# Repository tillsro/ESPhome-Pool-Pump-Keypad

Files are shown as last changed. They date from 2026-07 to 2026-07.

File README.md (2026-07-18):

# iLiving / Lingxiao Variable-Speed Pool Pump Controller

This repository documents and implements the proprietary RS-485 link between
the removable keypad and motor controller in an **iLiving ILG8PP390-VS** pool
pump. It contains:

- a PowerShell controller proven against the real pump;
- an ESPHome component for an M5Stack AtomS3 and Atomic RS485 Base;
- a PC pump emulator for testing either the AtomS3 or original keypad; and
- logic captures and keypad firmware analysis used to recover the protocol.

This project began with a more conventional approach. The iLiving manual
advertises an external RS-485 mode compatible with Pentair automation, so we
first tried the existing
[`gazoodle/CenturyVSPump`](https://github.com/gazoodle/CenturyVSPump) ESPHome
component. That project controls Century/Regal VGreen-style motors after they
are placed into a specific automation protocol mode. We could not put the
tested iLiving pump into any state that accepted those commands. Rather than
continue guessing at an inactive external interface, we switched to the link
we could prove was working: communication between the removable keypad and the
motor controller. Emulating that keypad became the basis of this project.

The protocol is not standard Modbus RTU. It uses a Modbus CRC-16, but it has no
Modbus address, function code, or register map.

## Safety

Pool pumps combine mains voltage, water, rotating equipment, and stored charge.
Work on the low-voltage communication connector only, with pump power removed
while changing wiring. Follow the pump manual and use a qualified electrician
for mains wiring.

- Disconnect the original keypad before another device transmits on its bus.
- Never connect two RS-485 transmitters to the pump at the same time.
- Do not connect the pump cable's `+5V` wire to the Waveshare adapter.
- Do not connect the pump's `+5V` wire to the Atomic base's `DC24V` terminal.
- Confirm polarity and protocol passively before sending commands to an
  untested model.
- The supplied ESPHome configuration defaults to sending a stop demand after
  boot. Read its startup-mode notes before installing it on operating equipment.

This is an independent reverse-engineering project. It is not affiliated with
or endorsed by iLiving, Guangdong Lingxiao Pump Industry, M5Stack, or the other
brands named below.

## Current Status

| Path | Result |
|---|---|
| Waveshare USB-RS485 -> real ILG8PP390-VS | **Confirmed:** complete replies, 1400/1800/2000 RPM, stop, and restart |
| Original keypad -> real ILG8PP390-VS | **Confirmed:** captured and decoded at startup, prime, presets, custom speeds, and stop |
| AtomS3 + Atomic RS485 Base -> PC emulator | **Confirmed:** 204/204 requests accepted in the recorded bench run; start, stop, RPM ramping, faults, and offline handling tested |
| Original keypad -> PC emulator | **Confirmed:** prime behavior and all 11 documented faults tested |
| AtomS3 + Atomic RS485 Base -> real pump | **Confirmed:** direct communication and pump control using pump `485A+` -> Atomic `A` and pump `485A-` -> Atomic `B` |

The original keypad uses an STM32F030-family MCU. Its flash was read twice with
matching output at RDP Level 0, without erase, unlock, or write operations.

## How We Reverse Engineered It

After the external-automation approach failed, we did not have a known register
map or a service manual for the keypad link. We had a six-wire cable, a running
pump, and a detachable keypad whose traffic had to be observed without
disrupting it. The final protocol came from combining electrical measurements,
controlled captures, failed replay experiments, firmware analysis, and
physical pump tests. No single method was sufficient by itself.

### Hardware and tools

| Item | How it was used |
|---|---|
| iLiving `ILG8PP390-VS` and original keypad | Reference system for every known-good state and final command test |
| Breakout connector and soldered PCB tap points | Allowed the keypad to be connected or isolated while the bus was monitored |
| Waveshare USB TO RS485 adapter | Captured byte streams and later transmitted generated pump commands |
| FX2LP Saleae-compatible logic analyzer | Passively observed both differential pairs and verified baud rate, polarity, and timing |
| ST-Link V2 clone | Read the keypad MCU and inspected live SRAM over SWD |
| STM32CubeProgrammer 2.22 | Identified the MCU, checked RDP, read flash, and performed read-only HotPlug memory inspection |
| PulseView and `sigrok-cli` | Recorded and decoded the logic-analyzer captures |
| PowerShell | Automated repeated captures, timestamped serial logging, frame replay, timing, and reply validation |
| Python | Implemented the stateful pump emulator and repeatable protocol tests |
| M5Stack AtomS3 and Atomic RS485 Base | Exercised the ESPHome controller against both the PC emulator and real pump |

### Establishing the physical bus

The keypad harness is labeled `485A+`, `485A-`, `485B+`, `485B-`, `GND`, and
`+5V`. The first byte captures were misleading because the keypad was talking
without a pump and was already in its communication-error behavior. We also
learned that matching the Waveshare `A+` and `B-` labels directly to the pump
labels inverted the data. The working mapping had to be established
empirically and then checked against the logic analyzer.

Once tap points and a disconnectable harness were available, the logic analyzer
could listen while the original keypad and pump communicated normally. The
Waveshare was disconnected during passive captures so it could not contend for
the bus. Probing all four data wires showed that normal keypad polling was on
the `485A` pair. The `485B` pair remained silent during those captures.

One especially useful experiment was to unplug the keypad while leaving the
pump running and listen to the bus. The pump sent nothing by itself. That
established that the keypad is the polling master and the drive only replies
after a request. It also explained why simply opening a serial port and waiting
could never discover the pump protocol.

### Capturing behavior instead of guessing fields

The inexpensive FX2LP analyzer could record only about 600 ms before hitting
its capture limit. `loop-capture.ps1` worked around that limitation by launching
many short `sigrok-cli` captures back to back. We recorded the pump in known
states rather than collecting one long, unlabeled trace: each preset, custom
speeds from 1000 through 3450 RPM, a speed transition, a complete shutdown, a
power-on transition, and the start of the ten-minute prime cycle.

Those controlled changes let us correlate bytes with real behavior. They also
established the approximately 61 ms request cadence and the pump's reply timing.
The shutdown and startup captures were particularly valuable because they
contained state transitions that did not appear at a steady speed.

### The convincing 9600-baud false lead

Our first UART decode at 9600 baud produced repeatable-looking `B5`, `A5`, `BD`,
and `F6` messages. Some apparent requests were three bytes, others four or five.
Because the same patterns appeared across captures, they looked like a real
variable-length protocol. We classified the messages, replayed captured prime
sequences, and tried to associate individual bytes with speed.

The pump did not accept those replays. Several practical mistakes made the
failure harder to interpret: some early emulator tests still had the original
keypad transmitting on the bus, and `Start-Sleep -Milliseconds 1` on Windows
actually introduced delays around 15 ms, far too coarse for the observed
timing. After eliminating bus contention and replacing sleeps with stopwatch
timing, the replay still failed. That forced us to question the decode itself.

The important lesson was that a UART alias can look structured and repeatable.
The apparent 9600-baud frames were a decoding artifact, not random noise, so
frequency tables and repeated patterns alone were not enough to validate them.

### Reading the keypad firmware safely

The keypad PCB exposed pads labeled `NRST`, `SWD`, `SWK`, `GND`, and `3.3V`.
Before connecting the ST-Link, we treated `3.3V` as the debugger's target-voltage
reference and explicitly avoided any unlock or erase operation. STM32CubeProgrammer
identified an STM32F05x/F030x8-class Cortex-M0 with 64 KB of flash and RDP Level
0. Two complete reads produced the same SHA-256 hash, giving us a verified
backup before any live inspection.

Static firmware analysis found two initialized UART stacks. `USART2` built a
request roughly every 60 ms and had a recognizable transmit buffer. `USART1`
used a separate parser and command family, which is why the silent `485B` pair
is still treated as a possible service or external-control interface rather
than declared unused.

Read-only HotPlug SRAM reads then connected the firmware to physical keypad
actions. While the keypad remained attached to the real pump, selecting the
three presets changed the `USART2` value field to `0x0C3A`, `0x0982`, and
`0x1770`, corresponding to 1800, 1400, and 3450 RPM on this keypad. The live
buffer showed a 12-byte structure beginning with `01 70`, a sequence byte, a
big-endian demand value, and a little-endian additive checksum. Comparing more
speeds revealed the scaling rule `floor(RPM * 6000 / 3450)`.

This was the point where firmware became a second source of truth. It disproved
the old 9600-baud interpretation and gave us exact bytes to search for in the
electrical captures. Re-decoding the bus at 38400 baud with the correct inverted
polarity exposed the same `01 70` traffic on the wire.

### Finding the missing on-wire bytes

The firmware buffer explained the first 12 bytes but not the whole transmitted
request. Comparing candidate frames with the captured tail bytes showed that a
standard Modbus CRC-16 was appended after the additive checksum. The complete
request was therefore 14 bytes, not 12. The same construction appeared at the
end of the pump response: 34 data bytes, a two-byte additive checksum, and a
two-byte Modbus CRC, for 38 bytes total.

That correction was the breakthrough. A replay containing the 12-byte inner
frame plus the CRC received a valid 38-byte response on its first request. The
reply parser was then made deliberately strict: it searches arbitrary serial
chunks for `01 70`, checks the expected sequence and shape, verifies the
additive checksum, and finally verifies the CRC. Single `00` bytes and partial
USB reads are treated as noise instead of pump acknowledgements.

### Proving control on the real pump

With the original keypad disconnected, the Waveshare sent sustained 14-byte
requests at the observed cadence. The pump returned complete replies and was
physically confirmed at 1400, 1800, and 2000 RPM. A zero demand stopped the
motor, and a later 1800 RPM demand restarted it. One timing soak returned 120
valid replies for 120 requests with no noise bytes.

Those tests also identified useful reply fields. The pump reports its accepted
demand at bytes `12..13`, an actual-speed value at `14..15`, and an echo of the
requested demand at `32..33`. Stop and restart captures showed those fields
ramping down and back up with the motor rather than changing only in software.

### Testing both sides without the pump

After the real control path worked, `pump_emulator.py` was built from a captured
38-byte response. It validates keypad/controller requests, echoes the sequence
and demand, simulates acceleration and deceleration, and can inject dropped
replies, bad CRCs, offline periods, and documented fault codes.

Connecting the original keypad to that emulator provided an independent test of
the reply direction. The keypad entered prime, commanded 3450 RPM, accepted the
simulated speed ramp, and displayed all 11 injected fault codes. It also exposed
the keypad's fault workflow: one power-button press acknowledges the error and
leaves the pump off; a second press starts prime again.

Finally, the AtomS3 and Atomic RS485 Base were connected to the same emulator.
The recorded bench run accepted and answered 204 of 204 requests while the
display followed stop, ramp, run, fault, and offline states. Protocol fixtures
and Python tests now preserve the request, reply, checksum, CRC, scaling, fault,
and stream-recovery behavior that was learned from the hardware.

The AtomS3 was then connected to the real pump with pump `485A+` wired to Atomic
`A`, pump `485A-` wired to Atomic `B`, and a shared ground. Direct communication
and pump control were confirmed on 2026-07-15. This closes the final
AtomS3-to-real-pump validation gap while keeping the PC emulator available for
tests that do not need a running motor.

## Protocol Summary

### Electrical and timing

- Physical layer: half-duplex RS-485
- Active keypad pair: `485A+` / `485A-`
- Serial format: 38400 baud, 8 data bits, no parity, 1 stop bit
- Request cadence: approximately 61 ms
- Keypad role: master; the pump remains silent until polled
- Request length: 14 bytes
- Reply length: 38 bytes

The earlier apparent 9600-baud `B5/A5/BD/F6` traffic was a logic-analyzer decode
alias. Valid captures decode as 38400 8N1 with inverted polarity on the probed
`485A+` channel.

### Request

```text
01 70 <seq> <status> 00 0C 00 00 <value_hi> <value_lo> <sum_lo> <sum_hi> <crc_lo> <crc_hi>
```

| Bytes | Meaning |
|---|---|
| `0..1` | Fixed header `01 70` |
| `2` | Sequence number |
| `3` | Status/control byte; zero in the validated command path |
| `4..7` | Fixed shape bytes `00 0C 00 00` |
| `8..9` | Big-endian speed demand value |
| `10..11` | Little-endian 16-bit sum of bytes `0..9` |
| `12..13` | Little-endian Modbus CRC-16 of bytes `0..11` |

The speed conversion is:

```text
value = floor(RPM * 6000 / 3450)
RPM   = value * 3450 / 6000
```

`value = 0` stops the motor. Known values include `0x0982` for 1400 RPM,
`0x0C3A` for 1800 RPM, and `0x1770` for 3450 RPM.

### Reply

The complete reply is validated before any state is accepted:

| Bytes | Meaning used by this project |
|---|---|
| `0..1` | Header `01 70` |
| `2` | Echoed sequence |
| `3` | Pump fault code, zero when clear |
| `4..5` | Shape bytes `00 0C` |
| `12..13` | Accepted demand value, big-endian |
| `14..15` | Actual speed value, big-endian |
| `32..33` | Echoed demand value, big-endian |
| `34..35` | Little-endian 16-bit sum of bytes `0..33` |
| `36..37` | Little-endian Modbus CRC-16 of bytes `0..35` |

Several reply fields remain unnamed. Captures from more operating conditions
are welcome; do not assign meanings from a single changing sample.

## Internal Keypad Bus vs. External Automation

The iLiving manual describes an external RS-485 mode compatible with Pentair
automation and says external keypad and RS-485 control are mutually exclusive.
That interface must not be confused with the internal `01 70` keypad protocol
implemented here.

Before reverse-engineering the internal bus, we attempted to use
[`CenturyVSPump`](https://github.com/gazoodle/CenturyVSPump) through that
documented external-control path. We were never able to place the tested pump
in a mode that accepted its commands. This does not show that the upstream
component is faulty; it shows only that its expected Century/Regal automation
mode was not accessible on our iLiving hardware. The known-active keypad bus
therefore became the practical control path.

The removable keypad cable has two differential pairs. `485A` carries the
confirmed `01 70` traffic. `485B` is silent during normal passive captures, but
the dumped keypad firmware initializes a second UART and a separate command
parser. It is plausible that this relates to an external or service interface,
but its physical mapping and protocol have not been proven.

Pentair, Jandy, and Hayward pumps are therefore **not** implied to be compatible
with this project merely because related Lingxiao pumps can connect to those
automation systems.

## Compatibility Research

Research was last refreshed on **2026-07-13**. Compatibility labels mean:

- **Confirmed**: this exact model exchanged valid `01 70` frames on hardware.
- **OEM-family candidate**: manufacturer documentation, certification data, or
  an FCC model declaration places it in the same pump family. The internal bus
  still needs a passive capture before use.
- **Similar-controller candidate**: the keypad, operating behavior, and fault
  table closely match, but no direct OEM-family declaration was found.

| Confidence | Brand / series | Models | Evidence | Internal `01 70` protocol |
|---|---|---|---|---|
| Confirmed | iLiving | `ILG8PP390-VS` | Physical captures, firmware analysis, and successful control in this repository | Confirmed |
| OEM-family candidate | iLiving | `ILG8PP130-VS`, `ILG8PP220-VS` | Same official three-model manual, controller description, speed range, prime behavior, and fault table | Unverified |
| OEM-family candidate | LX / Key Lander | `SHP130-VS`, `SFP220-VS`, `SWP390-VS` | Lingxiao product/certification records and the same model-family manuals | Unverified |
| OEM-family candidate | Lingxiao Relaax | `Relaax130-VS`, `Relaax220-VS`, `Relaax390-VS` | Manufacturer identity, matching certifications, and Lingxiao's FCC model declaration | Unverified; revision risk |
| OEM-family candidate | Trevi / Innovaqua | `SPH130-VS`, `SPH220-VS`, `SPH390-VS` | Official manual has the same controller, defaults, 10-minute prime, and 11-code fault table; Trevi lists the underlying `SFP220-VS` / `SWP390-VS` model names | Unverified |
| OEM-family candidate | Aqua Expert | `VSP13-Pro`, `VSP22-Pro`, `VSP39-Pro` | Included in Lingxiao's FCC model declaration and matching ENERGY STAR performance records | Unverified; current products add Wi-Fi |
| OEM-family candidate | Illuminex AquaPump | `LU-VS130`, `LU-VS220`, `LU-VS390` | Included in Lingxiao's FCC model declaration; official manual and specifications match the family | Unverified; current products add Wi-Fi |
| Similar-controller candidate | Trevoli SPV | `SPV100`, `SPV200`, `SPV300` | Distributor manual shows the same 1.3/2.2/3.9 HP grouping, 450-3450 RPM range, keypad behavior, prime cycle, defaults, and fault table | Unverified; OEM relationship not established |

The EPA ENERGY STAR dataset gives the iLiving, Lingxiao/LX/Key Lander, Trevi,
and Aqua Expert equivalents identical certified performance values within each
horsepower class. For example, all researched 3.9 HP entries report WEF `7.262`,
HHP `1.808`, and the same low/high test-point RPM and flow values. This is strong
evidence of a shared hydraulic and drive platform, but it is not proof that every
controller revision runs the same serial firmware.

### Revision risk

The newer Lingxiao manual filed with the FCC groups all three horsepower classes
and the iLiving, Relaax, SPH, VSP, and LU aliases under one model declaration.
It also adds Smart Life Wi-Fi support and fault codes not present in the older
iLiving keypad manual (`E030`, `E040`, `E095`, and `LOF`). A visually identical
or identically named pump may therefore contain a newer controller revision.

No public implementation or register map for the internal `01 70` protocol was
found under the researched iLiving or Lingxiao model numbers. Do not describe
this protocol as a known Modbus register set.

## Identifying Another Pump Safely

1. Record the exact brand, model, serial label, controller label, keypad photos,
   connector labels, and manual revision.
2. Compare its speed range, preset defaults, 10-minute prime behavior, and fault
   table with the documents linked below.
3. With pump power off, identify ground and measure supply voltage before
   attaching any analyzer. Do not infer pinout from wire color.
4. Reconnect the original keypad and capture passively. A logic analyzer may
   listen in parallel, but a USB-RS485 adapter must not transmit.
5. Look for 14-byte `01 70` requests every approximately 61 ms at 38400 8N1 and
   38-byte replies with valid additive checksums and Modbus CRC-16.
6. If that fingerprint differs, stop. Add a new protocol variant instead of
   trying this controller unchanged.
7. For a matching fingerprint, disconnect the keypad and make the first active
   test with a zero-speed demand while watching the pump and serial reply.

To test only a detached keypad without connecting its pump, follow the
[`Offline Keypad Compatibility Test`](docs/keypad-compatibility-test.md). It
checks both validated keypad requests and the keypad's handling of complete
speed, state, and fault replies.

Appearance alone is not enough. Product certification tables can also place
unrelated models next to one another; only explicit family evidence and a bus
capture should move a model into the supported list.

## Hardware and Wiring

### Proven Waveshare-to-pump wiring

The following mapping is specific to the labels on the tested iLiving harness:

| Pump cable | Waveshare USB TO RS485 |
|---|---|
| `485A-` | `A+` |
| `485A+` | `B-` |
| `GND` | `GND` |
| `+5V` | Not connected |
| `485B+`, `485B-` | Not connected for normal keypad emulation |

The crossed labels were established empirically on this pump. They do not mean
all RS-485 products use reversed labels.

For passive logic capture, the tested channel assignment is:

| Pump cable | Logic analyzer |
|---|---|
| `485A-` | `D0` |
| `485A+` | `D1` |
| `485B-` | `D2` |
| `485B+` | `D3` |
| `GND` | `GND` |

The usable UART stream decodes on `D1` with RX inversion enabled.

### Proven AtomS3-to-pump wiring

This mapping was validated on the real iLiving ILG8PP390-VS on 2026-07-15:

| Pump cable | Atomic RS485 Base |
|---|---|
| `485A+` | `A` |
| `485A-` | `B` |
| `GND` | `G` |
| `+5V` | Not connected |
| `485B+`, `485B-` | Not connected |

Power the AtomS3 through USB-C. Leave the Atomic base's `DC24V` terminal
disconnected; the pump's `+5V` wire is not a suitable input for that terminal.

### PC emulator to Atomic RS485 Base

For an isolated bench setup with no pump or keypad connected:

| Waveshare USB-RS485 | Atomic RS485 Base |
|---|---|
| `A+` | `A` |
| `B-` | `B` |
| `GND` | `G` |

Power the Waveshare and AtomS3 through their own USB connections. Leave the
Atomic base's `DC24V` terminal disconnected.

### Hardware photos and M5Stack adapter plate

These photos document the tested pump electronics, communication connector,
and the finished AtomS3 installation. The controller is mounted in a custom
3D-printed adapter plate that measures 115 x 115 mm overall and holds the
AtomS3 and Atomic RS485 Base behind the panel.

This is the original removable iLiving keypad used for the protocol captures,
STM32 firmware analysis, real-pump reference tests, and offline emulator tests:

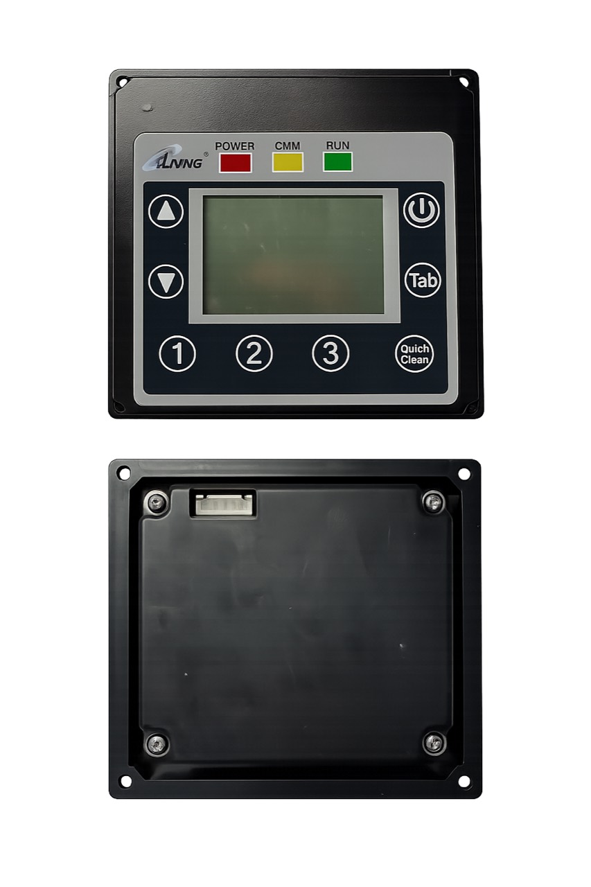
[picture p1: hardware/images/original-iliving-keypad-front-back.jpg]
Front and rear views of the original iLiving pool pump keypad


| Pump controller board | Communication connector detail |
|---|---|
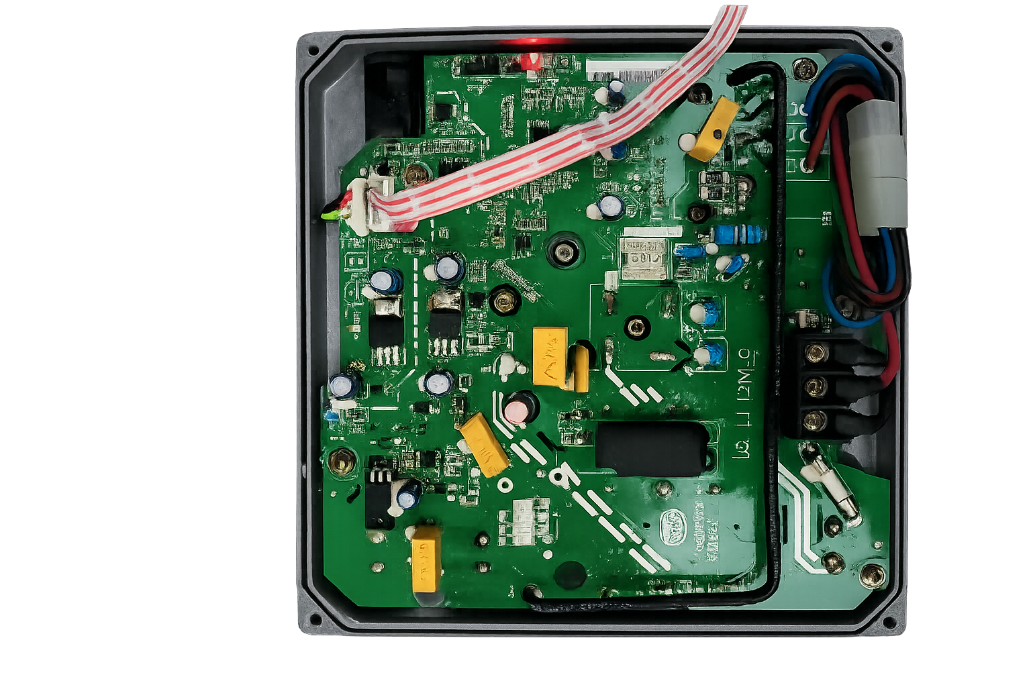
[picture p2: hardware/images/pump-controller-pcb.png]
Pump controller board inside its enclosure
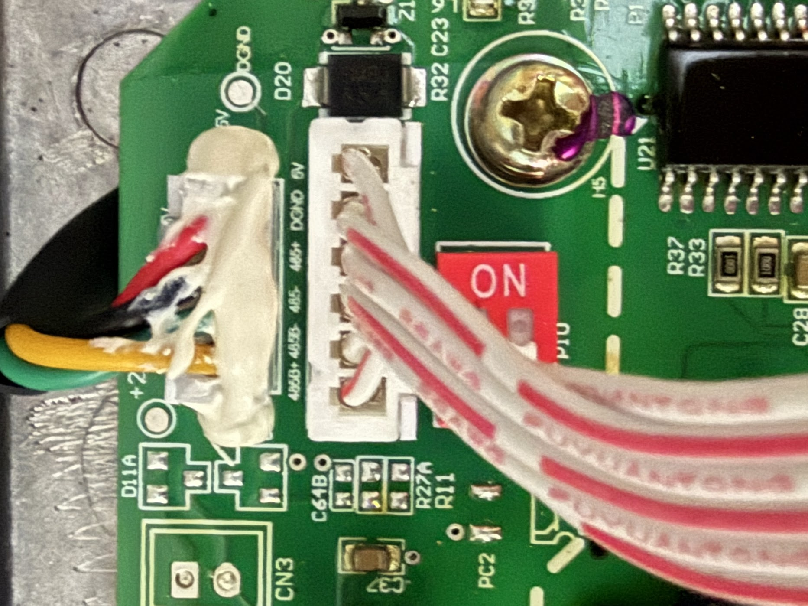
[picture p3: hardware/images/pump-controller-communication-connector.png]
Close-up of the pump controller communication connector and PCB labels
|  |  |

| Finished adapter plate | Adapter plate interior |
|---|---|
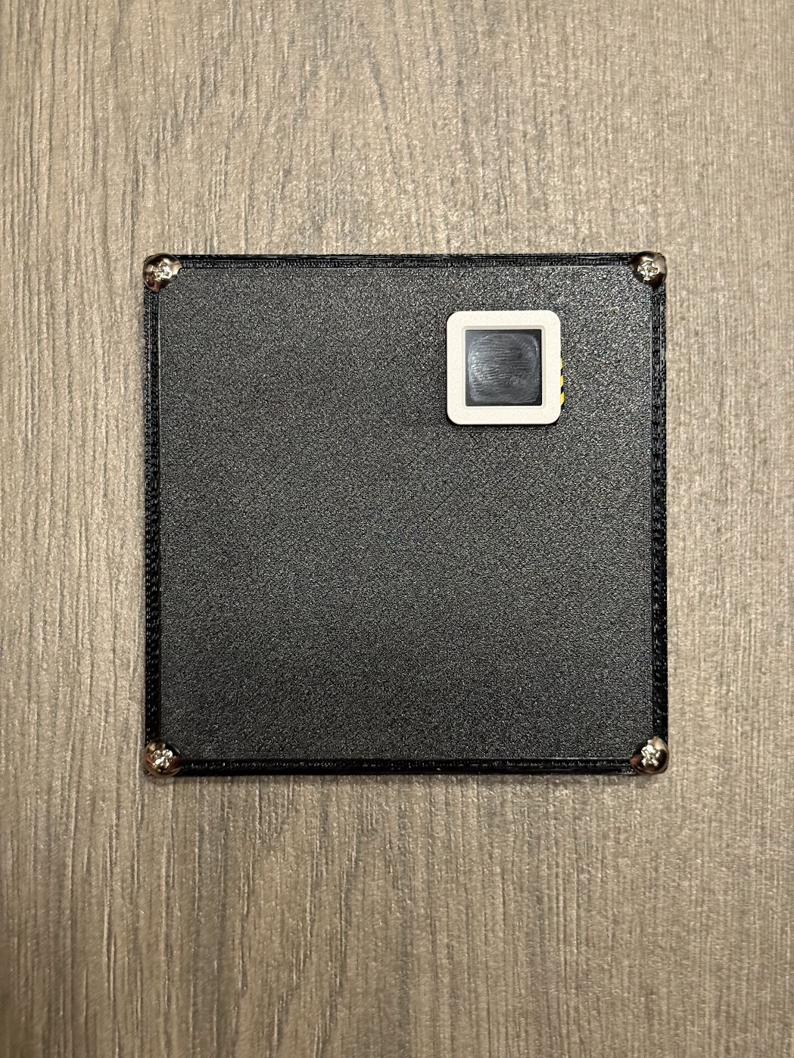
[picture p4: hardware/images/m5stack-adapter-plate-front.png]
Front of the printed M5Stack adapter plate with AtomS3 installed
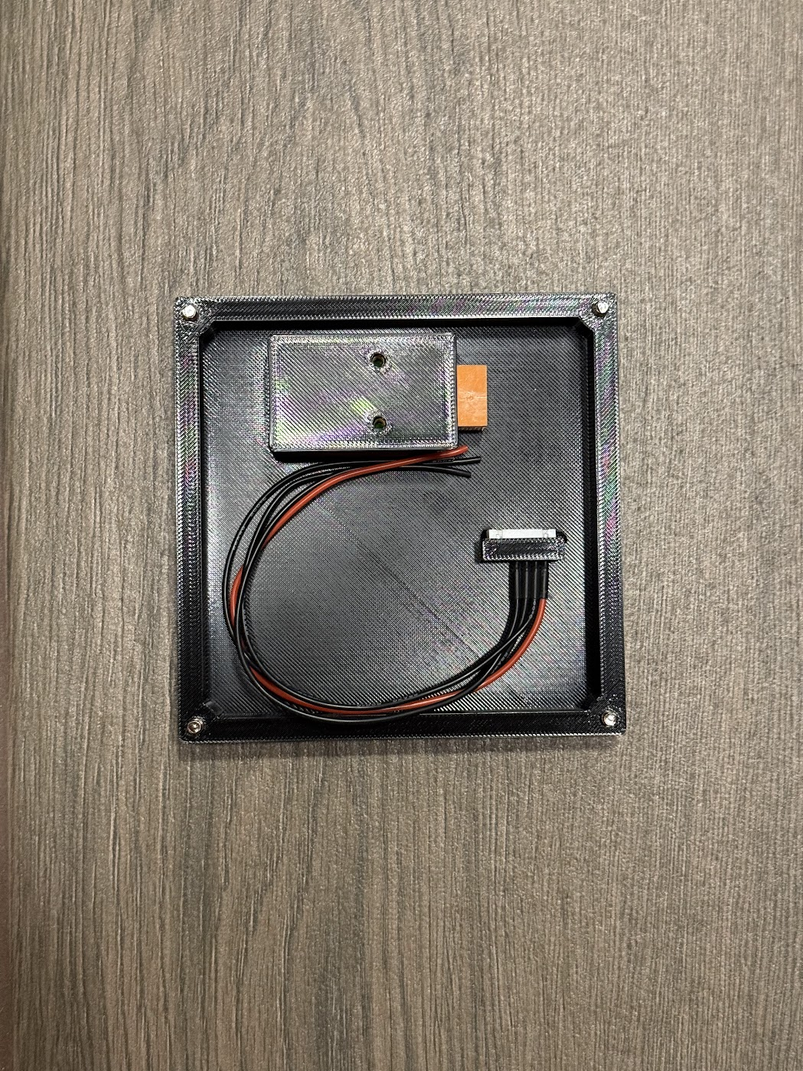
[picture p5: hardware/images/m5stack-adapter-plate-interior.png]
Inside of the printed M5Stack adapter plate with the RS485 hardware and cable
|  |  |

#### Completed pump installation

The finished wiring keeps the Atomic RS485 Base, connector adapter, and cable
inside the printed plate. The assembled plate then mounts in the pump control
enclosure with the AtomS3 screen and button accessible from the front.

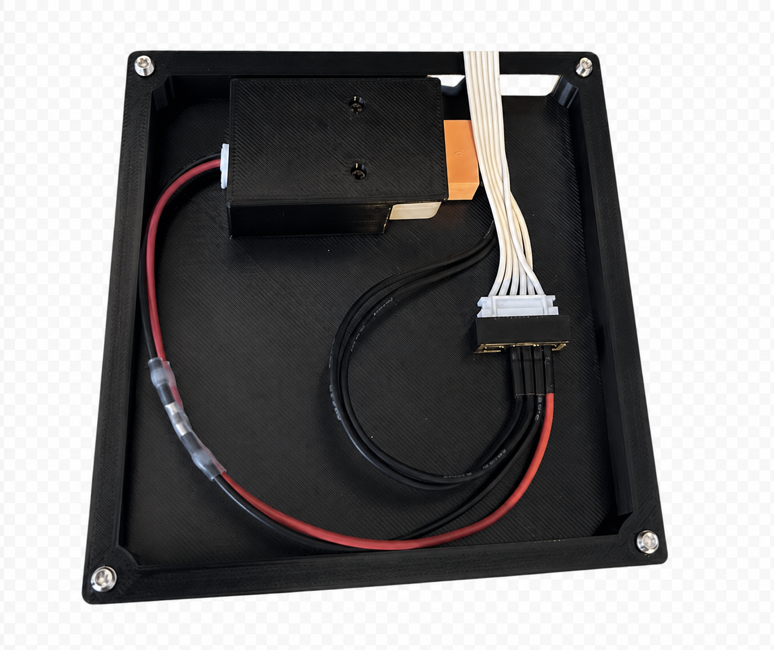
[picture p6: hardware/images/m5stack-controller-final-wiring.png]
Final internal wiring for the AtomS3 and Atomic RS485 Base


| Installed controller stopped | Installed controller running at 1800 RPM |
|---|---|
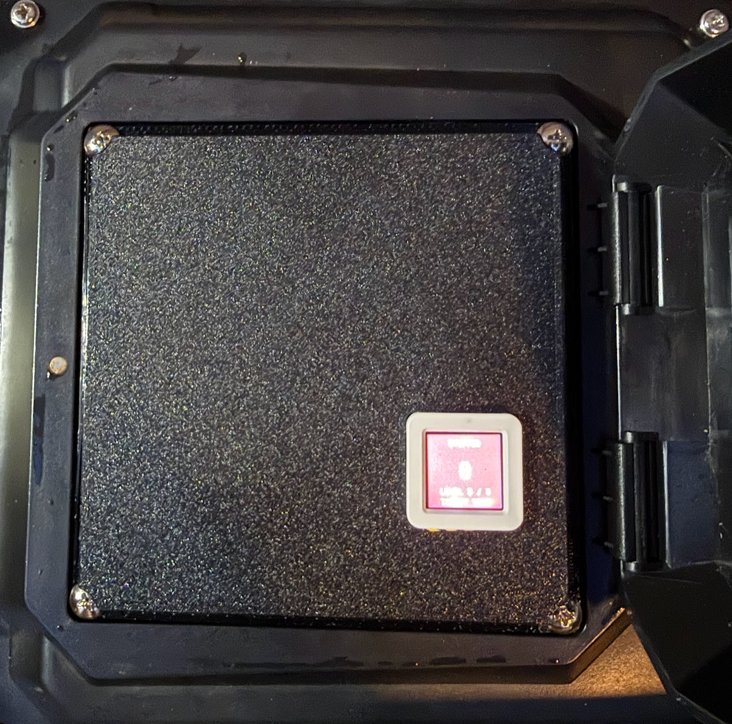
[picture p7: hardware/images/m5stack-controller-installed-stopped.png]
Completed M5Stack controller installed in the pump enclosure and stopped
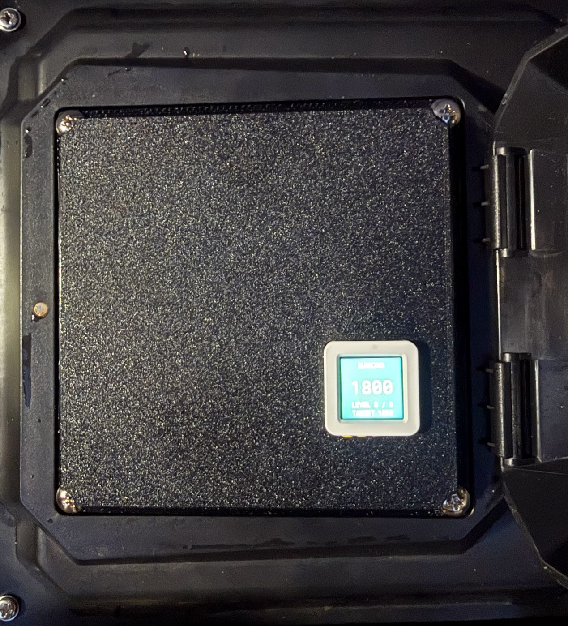
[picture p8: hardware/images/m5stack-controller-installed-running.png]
Completed M5Stack controller installed in the pump enclosure and running at 1800 RPM
|  |  |

| Running screen | Stopped screen |
|---|---|
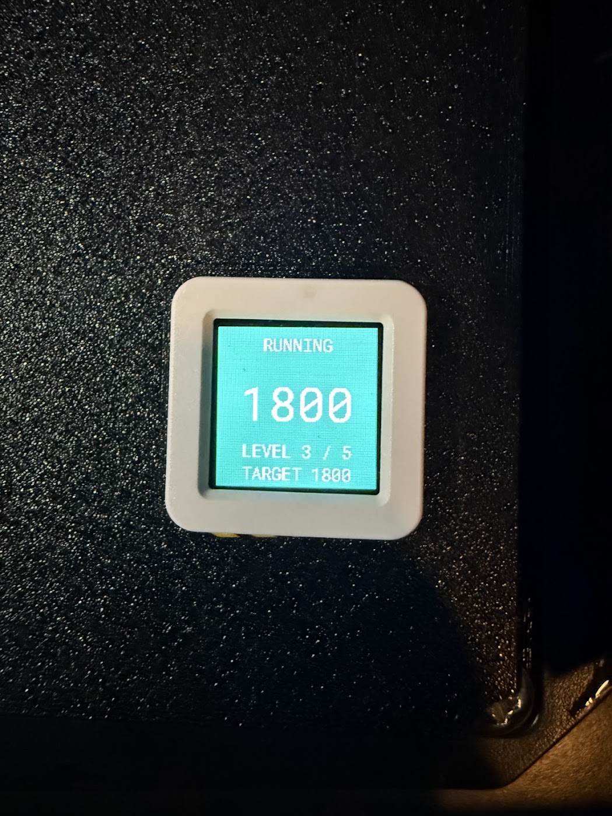
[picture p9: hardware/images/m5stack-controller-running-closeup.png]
AtomS3 running screen showing 1800 RPM at level 3 of 5
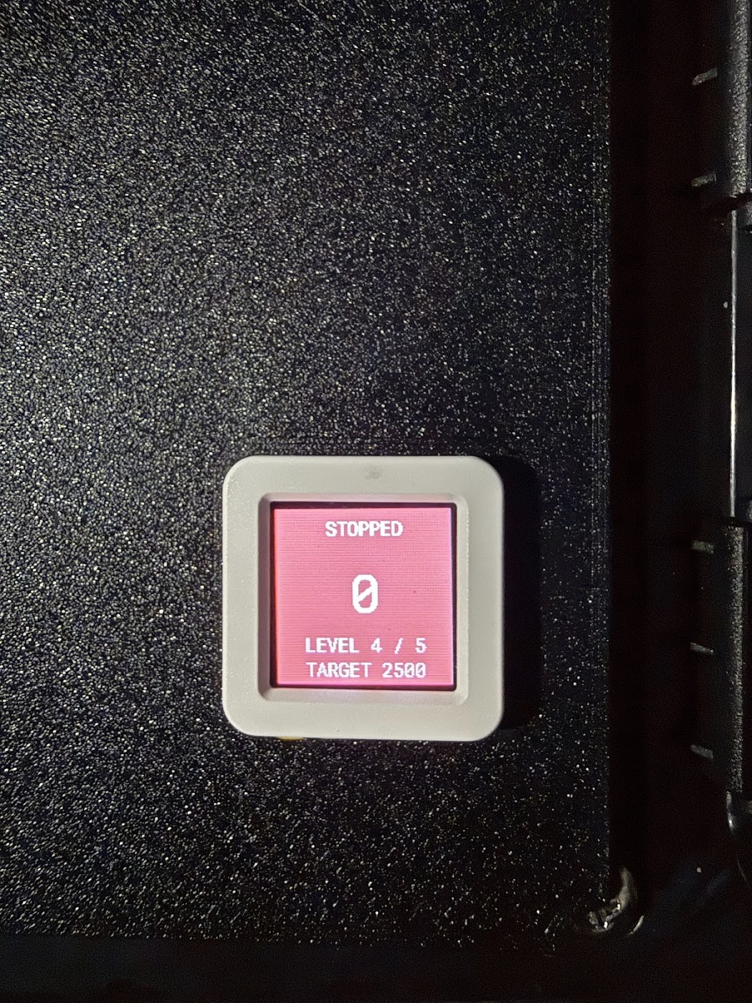
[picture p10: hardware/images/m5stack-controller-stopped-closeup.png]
AtomS3 stopped screen showing zero RPM and a 2500 RPM target
|  |  |

The enclosure design files are ready to download or modify:

- [M5Stack Pump Adapter Plate STEP model](hardware/cad/m5stack-pump-adapter-plate.step)
- [M5Stack Pump Adapter Plate dimensioned drawing (PDF)](hardware/cad/m5stack-pump-adapter-plate-drawing.pdf)

The drawing uses millimeters and shows the 115 x 115 mm plate, 24.2 x 24.2 mm
AtomS3 opening, and 4 mm corner mounting holes. Check the dimensions against
your enclosure before printing or drilling.

## Fresh-Clone Setup

The validated development environment uses Python 3.12 and ESPHome `2026.6.5`.
The pinned development requirements include both ESPHome and the lightweight
PC-emulator dependency.

On Windows PowerShell:

```powershell
git clone https://github.com/tillsro/ESPhome-Pool-Pump-Keypad.git
Set-Location .\ESPhome-Pool-Pump-Keypad
py -3.12 -m venv .venv
& '.\.venv\Scripts\python.exe' -m pip install --upgrade pip
& '.\.venv\Scripts\python.exe' -m pip install -r requirements-dev.txt
Copy-Item .\esphome\secrets.example.yaml .\esphome\secrets.yaml
```

On macOS or Linux:

```bash
git clone https://github.com/tillsro/ESPhome-Pool-Pump-Keypad.git
cd ESPhome-Pool-Pump-Keypad
python3.12 -m venv .venv
. .venv/bin/activate
python -m pip install --upgrade pip
python -m pip install -r requirements-dev.txt
cp esphome/secrets.example.yaml esphome/secrets.yaml
```

The example secrets are sufficient for validation, but replace every
placeholder with a unique value before flashing hardware. From the repository
root, verify the protocol fixtures and ESPHome configuration:

```powershell
& '.\.venv\Scripts\python.exe' -m unittest tests.test_pump_emulator -v
& '.\.venv\Scripts\esphome.exe' config .\esphome\pool-pump-controller.yaml
```

For a complete firmware build on Windows, keep generated files outside a path
containing spaces:

```powershell
$env:ESPHOME_BUILD_PATH = "$env:USERPROFILE\.esphome-build"
& '.\.venv\Scripts\esphome.exe' compile .\esphome\pool-pump-controller.yaml
```

The same test, validation, and compile steps run automatically in GitHub
Actions for every push and pull request.

## Quick Start

### Probe or control the real pump with the Waveshare

Confirm that the keypad is disconnected and only the three proven Waveshare
wires are attached. Replace `COM3` as needed.

Probe communication with a stop demand and exit after the first complete reply:

```powershell
powershell -NoProfile -ExecutionPolicy Bypass -File ".\replay-firmware-master-frame.ps1" `
  -Port COM3 -Rpm 0 -Cycles 50 -StopOnMeaningfulReply
```

Send a sustained 1800 RPM command:

```powershell
powershell -NoProfile -ExecutionPolicy Bypass -File ".\replay-firmware-master-frame.ps1" `
  -Port COM3 -Rpm 1800 -Cycles 300
```

The script rejects incomplete, malformed, checksum-failing, and CRC-failing
replies. It logs every transmitted frame and received byte.

### Run the PC pump emulator

List serial ports:

```powershell
powershell -NoProfile -ExecutionPolicy Bypass -File ".\run-pump-emulator.ps1" -ListPorts
```

Start the emulator:

```powershell
powershell -NoProfile -ExecutionPolicy Bypass -File ".\run-pump-emulator.ps1" -Port COM3
```

Run the automatic fault demonstration:

```powershell
powershell -NoProfile -ExecutionPolicy Bypass -File ".\run-pump-emulator.ps1" `
  -Port COM3 -FaultDemo -FaultHoldSeconds 3 -FaultClearSeconds 1 `
  -ExitAfterFaultDemo
```

See [`esphome/README.md`](esphome/README.md) for AtomS3 wiring, firmware build,
startup modes, web controls, emulator controls, and original-keypad fault tests.
For a repeatable compatibility test of another detached keypad, use
[`docs/keypad-compatibility-test.md`](docs/keypad-compatibility-test.md).

### Capture the keypad bus

The inexpensive FX2 logic analyzer used here is limited to approximately 600 ms
per capture. `loop-capture.ps1` repeatedly invokes `sigrok-cli` as a workaround:

```powershell
powershell -NoProfile -ExecutionPolicy Bypass -File ".\loop-capture.ps1" -Label "my-test"
```

Decode one capture with:

```powershell
& "C:\Program Files\sigrok\sigrok-cli\sigrok-cli.exe" `
  -i ".\capture.sr" `
  -P "uart:rx=D1:baudrate=38400:format=hex:invert_rx=yes" `
  -A "uart=rx-data"
```

## Documented Faults

The older iLiving manual and original keypad use these codes. The PC emulator
can inject each one:

| Code | Meaning |
|---|---|
| `E001` | IPM module failure |
| `E002` | Output current exceeds limit |
| `E006` | Input voltage too high |
| `E009` | Input voltage too low |
| `E010` | Inverter overload |
| `E011` | Motor overload |
| `E013` | Output phase loss or imbalance |
| `E014` | Inverter overheating |
| `E018` | Current sampling circuit failure |
| `E021` | Display-board EEPROM or connection failure |
| `E048` | PFC overcurrent or PFC circuit failure |

On the tested original keypad, the first fault remains latched. The first power
button press acknowledges it and leaves the pump off; the second press restarts
the prime sequence.

## Repository Map

| Path | Purpose |
|---|---|
| `replay-firmware-master-frame.ps1` | Known-good real-pump command and reply validator |
| `pump_emulator.py` | Stateful 38-byte pump emulator with RPM ramping and fault injection |
| `run-pump-emulator.ps1` | Windows launcher for the emulator |
| `requirements-emulator.txt` | Clean Python environment dependency for the emulator |
| `requirements-dev.txt` | Pinned Python and ESPHome development environment |
| `tests/test_pump_emulator.py` | Protocol, parser, reply, and emulator tests |
| `docs/keypad-compatibility-test.md` | Safe detached-keypad test and compatibility report procedure |
| `esphome/pool-pump-controller.yaml` | AtomS3 user configuration |
| `esphome/components/iliving_pump/` | Local ESPHome protocol component |
| `esphome/README.md` | AtomS3 build, wiring, and bench-test guide |
| `hardware/cad/` | STEP model and dimensioned PDF drawing for the M5Stack adapter plate |
| `hardware/images/` | Pump electronics, connector, and completed enclosure reference photos |
| `loop-capture.ps1` | Repeated FX2/sigrok logic capture |
| `scrape-rs485.ps1` | Timestamped USB-RS485 byte capture |
| `firmware-dumps/` | Read-only keypad firmware research artifacts; not required at runtime |
| `.github/` | CI, Dependabot, issue forms, and pull-request template |
| `CHANGELOG.md` | Release notes, confirmed hardware, and known limitations |
| `LICENSE` and `LICENSES/` | MIT software license and CC BY 4.0 documentation/media license |

## Tests

After completing [Fresh-Clone Setup](#fresh-clone-setup), run the Python
protocol fixtures from the repository root:

```powershell
& '.\.venv\Scripts\python.exe' -m unittest tests.test_pump_emulator -v
```

## Contributing Compatibility Reports

A useful report includes:

- exact brand and model number;
- photos of the pump label, controller, keypad front/back, and connector;
- manual URL and revision or document number;
- measured connector voltages and pin labels;
- a passive startup/idle/speed-change capture;
- decoded baud, polarity, request length, and reply length; and
- whether checksums and CRC match this implementation.

Do not publish extracted proprietary firmware unless you have redistribution
rights. Hashes, disassembly notes, and independently written protocol
descriptions are normally sufficient for compatibility work.

## Licensing

Software in this repository is licensed under the [MIT License](LICENSE).
Documentation, photographs, drawings, CAD, and non-firmware research notes are
licensed under the [Creative Commons Attribution 4.0 International
License](LICENSES/CC-BY-4.0.txt). See [the license scope](LICENSES/README.md) for
the file-level split and attribution guidance.

## Research Sources

- [iLiving ILG8PP390-VS product page](https://ilivingusa.com/products/ilg8pp390-vs)
- [iLiving ILG8PP130/220/390 manual](https://cdn.shopify.com/s/files/1/0557/0356/8589/files/H40403925_SHP130_SFP220_SWP390-VS_ILG8PP_V1.pdf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)
- [gazoodle/CenturyVSPump ESPHome component](https://github.com/gazoodle/CenturyVSPump)
- [Lingxiao Relaax390-VS official product page](https://lingxiaopumps.com/products/lingxiao-3-9hp-variable-speed-pool-pump-inground-230v-smart-pool-pump-relaax390-vs)
- [EPA ENERGY STAR certified pool-pump dataset](https://data.energystar.gov/Active-Specifications/ENERGY-STAR-Certified-Pool-Pumps/m8cf-pkii)
- [EPA ENERGY STAR record for LX SWP390-VS](https://www.energystar.gov/productfinder/product/certified-pool-pumps/details/2618813/export/pdf)
- [Lingxiao SFP220-VS FCC filing index](https://fccid.io/2BQZL-SFP220-VS)
- [FCC-filed Lingxiao model-difference declaration](https://fccid.io/2BQZL-SFP220-VS/Letter/Declaration-Letter-of-Model-Difference-8539011)
- [FCC-filed Lingxiao model-family manual](https://fccid.io/2BQZL-SFP220-VS/User-Manual/User-Manual-8539033)
- [Trevi Innovaqua VS-390 product page](https://trevi.com/en-us/products/vs-390-innovaqua-pump-40461)
- [Trevi Innovaqua variable-speed pump manual](https://trevi.com/cdn/shop/files/Guide-Innova-Pompes_variables_V5_bilingue.pdf?v=13996620635891541859)
- [Aqua Expert VSP pump family](https://canaxy.com/products/equipment/pool-pumps/)
- [Illuminex AquaPump LU-VS130/220/390 manual](https://illuminexpool.com/wp-content/uploads/2025/01/AquaPump-VS-User-Manual-EN_FR-1.pdf)
- [Trevoli SPV100/200/300 distributor manual](https://www.vortexdistributors.com/documents/SPV%20Series%202023.pdf)

## Release Status

`v0.1.0` is the first public-ready release. It includes the real-pump controller,
AtomS3 firmware, PC emulator, protocol tests, hardware documentation, and CAD
used for the validated installation. See [CHANGELOG.md](CHANGELOG.md) for the
confirmed hardware matrix and current limitations.

Compatibility remains intentionally conservative: the iLiving `ILG8PP390-VS`
is the only pump confirmed through direct control. Related Lingxiao and
rebadged models remain unverified until another owner provides a matching
passive capture or a complete offline keypad test.

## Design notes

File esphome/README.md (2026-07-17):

# AtomS3 iLiving pump controller

This configuration replaces the original Century/VGreen integration with a local
ESPHome component for the protocol validated on the iLiving ILG8PP390-VS.

## Protocol implemented

- 38400 baud, 8 data bits, no parity, 1 stop bit.
- A 14-byte `01 70` request every 61 ms.
- The keypad firmware's 16-bit additive checksum, followed by Modbus CRC-16.
- Complete 38-byte reply validation: header, echoed sequence, shape, additive
  checksum, and Modbus CRC-16.
- Demand scaling `floor(RPM * 6000 / 3450)`.
- Stop (`0`), start, 1000-3450 RPM demand, actual RPM, accepted RPM, online
  state, and decoded pump faults.

The compile-time protocol fixtures include the Waveshare-generated 1800 RPM
request and a complete pump reply from
`replay-rx-timing-soak-speed1-20260713_200032.log`.

## AtomS3 button controls

The AtomS3's front screen/button uses two distinct gestures:

- Short press (50-800 ms): start a stopped pump at the currently selected speed.
  While running, select the next speed level.
- Long press: stop the pump as soon as the hold reaches 1.5 seconds. Releasing
  the button is not required, and a long press never starts the pump.

Presses between 800 ms and 1.5 seconds do nothing. The five speed levels are:

| Level | Demand |
|---|---:|
| 1 | 1000 RPM |
| 2 | 1400 RPM |
| 3 | 1800 RPM |
| 4 | 2500 RPM |
| 5 | 3450 RPM |

The initial target is level 3 (1800 RPM). The first short press starts the pump
without advancing that target. Further short presses change speed immediately.
The screen shows both the selected level and target RPM. A custom demand set
through ESPHome or Home Assistant is labeled `CUSTOM SPEED`; while running, the
next short press selects the next higher preset, or wraps from level 5 to level
1. The five RPM values are kept in the `substitutions` block at the top of
`pool-pump-controller.yaml` so they can be changed in one place.

## Display heat and image-retention protection

The controller keeps the pump protocol and network services running while it
manages the LCD separately:

- After one minute without display activity, the backlight dims to 20% (or the
  configured brightness when it is already lower than 20%).
- After five total idle minutes, the backlight turns off, display refreshes are
  suspended, and the GC9107 receives `Display OFF` (`0x28`) and `Sleep IN`
  (`0x10`).
- The first short press while asleep only wakes the display. It does not start
  the pump or change speed. A 1.5-second hold still stops the pump and wakes the
  red stopped screen at the hold threshold.
- Pump run-state, speed, communication, and fault changes wake the display.
  Faults prevent automatic dimming or sleep until the fault clears.
- The `Screen Backlight` switch performs the same full sleep/wake sequence.
  `Screen Brightness` stores the level restored on wake; setting it to zero
  also sleeps the display.

The timings and dim level are substitutions at the top of
`pool-pump-controller.yaml`: `display_dim_after`,
`display_sleep_after_dimming`, and `display_dim_percent`. The second delay is
measured after dimming, so the defaults of one and four minutes produce a
five-minute total sleep timeout.

## Isolated Waveshare pump emulator

The PC can emulate the pump so the AtomS3 and Atomic RS485 Base can be tested
without the pump or keypad attached. Power both USB devices normally and use
three short jumper wires:

| Waveshare USB-RS485 | Atomic RS485 Base |
|---|---|
| `A+` | `A` |
| `B-` | `B` |
| `GND` | `G` |

Leave the Atomic base's `DC24V` terminal disconnected. Do not connect the pump,
keypad, or pump `+5V` wire anywhere in this setup. Use the straight-through
labels shown above. A logic-analyzer isolation test proved that crossing these
two adapters made their bias networks oppose one another and held the Atomic B
line high.

This bench wiring was validated on 2026-07-13: the emulator accepted and replied
to 204 of 204 AtomS3 requests, while the controller established communication
with no new missed replies.

After connecting the Waveshare to the PC, identify its port:

```powershell
powershell -NoProfile -ExecutionPolicy Bypass -File ".\run-pump-emulator.ps1" -ListPorts
```

Then start the emulator from the repository root, substituting the Waveshare's
port if it is not `COM3`:

```powershell
powershell -NoProfile -ExecutionPolicy Bypass -File ".\run-pump-emulator.ps1" -Port COM3
```

To exercise every keypad-derived pump fault automatically, hold each fault for
three seconds, clear it for one second, and exit after the final clear:

```powershell
powershell -NoProfile -ExecutionPolicy Bypass -File ".\run-pump-emulator.ps1" `
  -Port COM3 -FaultDemo -FaultHoldSeconds 3 -FaultClearSeconds 1 `
  -ExitAfterFaultDemo
```

The sequence covers `E001`, `E002`, `E006`, `E009`, `E010`, `E011`, `E013`,
`E014`, `E018`, `E021`, and `E048`. List their decoded descriptions without
opening a serial port with:

```powershell
powershell -NoProfile -ExecutionPolicy Bypass -File ".\run-pump-emulator.ps1" -ListFaults
```

The original keypad latches the first nonzero fault until its power button is
pressed once to acknowledge the error and a second time to restart. Use the
acknowledgement-gated mode when testing the keypad itself:

```powershell
powershell -NoProfile -ExecutionPolicy Bypass -File ".\run-pump-emulator.ps1" `
  -Port COM3 -KeypadFaultDemo -FaultHoldSeconds 3 -KeypadRecoverySeconds 2
```

For power verification, complete keypad wiring, normal command checks,
pass/fail criteria, and a report template, follow the dedicated
[`Offline Keypad Compatibility Test`](../docs/keypad-compatibility-test.md).

After each code appears, wait at least three seconds and press the keypad power
button twice. The emulator waits for the second press's nonzero demand before
advancing to the next code.

The AtomS3 should change from `OFFLINE` to `STOPPED`. Short-press its button to
request 1800 RPM; the display should show `RAMPING` and then `RUNNING`, with
actual RPM climbing at the configured rate. Use further short presses to test
all five speed levels, then hold for 1.5 seconds to test stopping. The display
should turn red at the 1.5-second threshold, even if the button is still held.

While the emulator console is active, these single-key controls are available:

| Key | Test action |
|---|---|
| `S` | Print current emulator state and counters |
| `F` | Cycle to the next documented pump fault |
| `C` | Clear the injected fault |
| `O` | Toggle all replies off/on to test the 500 ms offline fail-safe |
| `D` | Drop the next reply |
| `X` | Corrupt the next reply's CRC |
| `R` | Force actual RPM to zero without changing accepted demand |
| `V` | Toggle per-frame console output |
| `Q` | Stop the emulator |

Every request and reply is written to a timestamped ASCII log. The protocol
fixture tests can be rerun from the repository root with:

```powershell
& '.\.venv\Scripts\python.exe' -m unittest tests.test_pump_emulator -v
```

## Build

1. From the repository root, create the pinned Python 3.12 environment:

   ```powershell
   py -3.12 -m venv .venv
   & '.\.venv\Scripts\python.exe' -m pip install --upgrade pip
   & '.\.venv\Scripts\python.exe' -m pip install -r requirements-dev.txt
   ```

   See the root README for macOS and Linux commands. The validated requirement
   is ESPHome `2026.6.5`.

2. Copy `esphome\secrets.example.yaml` to `esphome\secrets.yaml` and replace
   every placeholder before flashing hardware.

3. On Windows, if the repository path contains spaces, point ESPHome's build
   output at a path without spaces before validating or compiling:

   ```powershell
   $env:ESPHOME_BUILD_PATH = "$env:USERPROFILE\.esphome-build"
   ```

   Pioarduino can reject generated project paths containing whitespace. This
   environment variable is optional on other installations.

4. Validate from the repository root:

   ```powershell
   & '.\.venv\Scripts\esphome.exe' config .\esphome\pool-pump-controller.yaml
   ```

5. Compile and upload over USB-C:

   ```powershell
   & '.\.venv\Scripts\esphome.exe' run .\esphome\pool-pump-controller.yaml
   ```

## Startup behavior

The supplied YAML uses `startup_mode: STOPPED`. After the one-second startup
delay, it continuously sends valid stop frames. This is deliberately
deterministic: rebooting the Atom while attached to the pump stops the motor.

`startup_mode: PASSIVE` sends no pump traffic until `Pump Run` is explicitly
changed. Because the pump is silent until polled, passive mode cannot know or
display the pump's physical state.

Use `startup_mode: RUNNING` only when automatic motor start after every
controller boot is explicitly desired. It commands the configured RPM after
each boot.

## Hardware

### Known-good Waveshare reference

Keep using `replay-firmware-master-frame.ps1` as the known-good protocol oracle.
Do not connect the Waveshare and Atom transmitters to the pump at the same time.

The proven Waveshare wiring remains:

| Pump cable | Waveshare terminal |
|---|---|
| `485A-` | `A+` |
| `485A+` | `B-` |
| `GND` | `GND` |
| `+5V` | Not connected |

The Waveshare labels are reversed relative to the pump cable labels. Do not
reuse this crossed mapping for the M5Stack base.

### Proven AtomS3/Atomic RS485 Base wiring

Power the AtomS3 from USB-C. On the Atomic base's four-position terminal, leave
the `DC24V` input disconnected; the pump's `+5V` wire is not a suitable input for
that terminal.

Use the following mapping:

| Pump cable | Atomic RS485 Base |
|---|---|
| `485A+` | `A` |
| `485A-` | `B` |
| `GND` | `G` |
| `+5V` | Not connected |

This wiring was validated against the real iLiving ILG8PP390-VS on 2026-07-15.
The AtomS3 established communication and controlled the pump successfully. Do
not cross `A` and `B` for this pump/base combination.

The base has no built-in 120-ohm termination. Leave termination out for the
short-cable connection, matching the validated setup.

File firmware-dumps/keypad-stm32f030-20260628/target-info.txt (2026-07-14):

Keypad STM32 firmware dump metadata
==================================

Date: 2026-06-28
Target board: iLiving ILG8PP390-VS detachable keypad
Probe/software: ST-Link V2 clone, STM32CubeProgrammer v2.22.0

Readout result
--------------
- Device identified by STM32CubeProgrammer as STM32F05x/F030x8.
- Device ID: 0x440.
- Flash/NVM size reported: 64 KBytes.
- CPU: Cortex-M0.
- Target voltage observed during successful read: about 3.31-3.32 V.
- Option bytes showed RDP 0xAA / Level 0, so flash readout was not protected.
- No write/erase/unlock operation was performed.

Dump files
----------
- keypad-flash-0x08000000-64k-read1.bin
- keypad-flash-0x08000000-64k-read2.bin
- keypad-firmware.bin: canonical copy of read1 for analysis.

Verification
------------
- read1 and read2 are both 65536 bytes.
- read1 SHA256: 010EB54D23D478BF094CB2AC2BA2B0880D778D2B6095476BEE09D7810DF5E7F7
- read2 SHA256: 010EB54D23D478BF094CB2AC2BA2B0880D778D2B6095476BEE09D7810DF5E7F7

Notes
-----
- After a reseat on 2026-06-28, STM32CubeProgrammer detected the ST-Link and target again.
- A read-only HotPlug SRAM check confirmed the live USART2 TX buffer contained 01 70 5B 00 00 0C 00 00 00 00 D8 00.
- If a later CLI call reports "No debug probe detected" while Windows still lists the ST-Link, first clear any stale STM32_Programmer_CLI process and re-run probe listing.
- Continue analysis from keypad-firmware.bin unless a newer dump is explicitly created.

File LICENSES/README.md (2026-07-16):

# License scope

Copyright (c) 2026 Robert Tills.

The repository uses two licenses:

- Software is licensed under the [MIT License](../LICENSE). This includes the
  Python, PowerShell, C++, ESPHome YAML, tests, workflows, and supporting
  configuration files.
- Documentation and media are licensed under the
  [Creative Commons Attribution 4.0 International License](CC-BY-4.0.txt).
  This includes Markdown documentation, photographs, the PDF drawing, STEP
  model, and firmware-research notes that do not contain extracted firmware.

Attribution for CC BY 4.0 material should identify Robert Tills and link to
this repository where reasonably practical. Product names, logos, and
trademarks remain the property of their respective owners. External resources
linked from the documentation are not part of this repository and are not
licensed here.

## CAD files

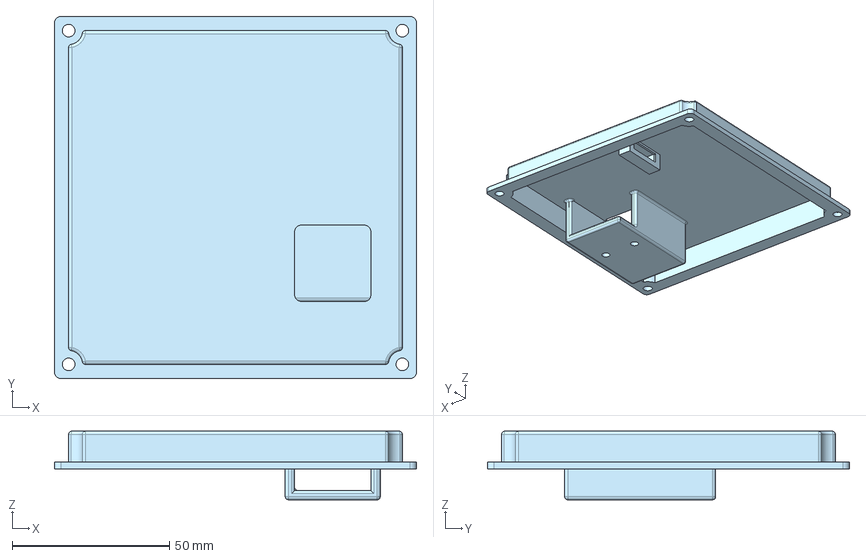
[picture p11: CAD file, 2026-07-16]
hardware/cad/m5stack-pump-adapter-plate.step
115.0 x 115.0 x 21.8 mm

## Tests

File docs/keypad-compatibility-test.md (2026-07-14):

# Offline Keypad Compatibility Test

This procedure tests a detached pump keypad against the PC pump emulator. It
can establish whether the keypad uses the same internal `01 70` request and
38-byte reply protocol as the iLiving ILG8PP390-VS without connecting the
candidate pump or running its motor.

Passing this test proves keypad-protocol compatibility. It does **not** prove
that the candidate pump drive uses the same pinout, voltage, firmware revision,
or external automation protocol.

## What the test checks

The emulator accepts only requests that match these framing and integrity
properties:

- 38400 baud, 8 data bits, no parity, 1 stop bit;
- 14-byte requests beginning with `01 70`;
- fixed request shape bytes `00 0C 00 00`;
- a valid 16-bit additive checksum;
- a valid Modbus CRC-16.

It then interprets the demand field using the `0..6000` scale for
`0..3450 RPM`. Values above that range are clamped by the simulated pump model,
so an implausible demand should be reported even if the frame itself validates.

It replies with the complete 38-byte frame captured from the real pump. The
test can also inject every documented fault code and verify that the keypad
understands the reply's fault field.

## Required equipment

- The detached keypad and its mating connector or a safe breakout harness.
- A Windows PC with Python 3.
- A Waveshare USB TO RS485 adapter or another automatic-direction USB-RS485
  adapter.
- A regulated, current-limited supply set to the keypad's **verified** supply
  voltage.
- A multimeter.
- Short jumper wires.
- Optional: a logic analyzer for investigating a failed or partial match.

Do not connect the pump, mains wiring, AtomS3, or another RS-485 transmitter
during this test.

## Verify power before wiring

The tested iLiving keypad harness has labeled `+5V` and `GND` pins. That fact
must not be generalized to an unknown keypad.

1. Find the keypad supply voltage in its service documentation, connector
   labels, or a measurement made by someone qualified to work around the pump.
2. Identify ground independently. Do not rely on wire color.
3. Set the bench supply to the verified voltage before connecting the keypad.
4. Use current limiting and stop immediately if the keypad draws unexpected
   current, repeatedly resets, becomes warm, or smells abnormal.

Do not power the keypad from the Waveshare adapter. Do not feed power into an
STM32 header pin labeled `3.3V`; that pin is normally the MCU rail or debugger
voltage reference, not the keypad's main power input.

The project has not established a universal safe current limit for other
keypads, so this guide intentionally does not prescribe one.

## Install the emulator

From the repository root in PowerShell:

```powershell
py -3 -m venv .venv
& '.\.venv\Scripts\python.exe' -m pip install --upgrade pip
& '.\.venv\Scripts\python.exe' -m pip install -r '.\requirements-emulator.txt'
```

The launcher automatically uses `.venv`. A specific Python interpreter can be
selected with `-PythonPath` if needed.

Plug in the Waveshare and list its serial port:

```powershell
powershell -NoProfile -ExecutionPolicy Bypass -File ".\run-pump-emulator.ps1" -ListPorts
```

On Linux or macOS, install the same requirement and invoke the Python script
directly, replacing the serial port as appropriate:

```bash
python3 -m venv .venv
. .venv/bin/activate
python -m pip install -r requirements-emulator.txt
python pump_emulator.py --list-ports
```

## Wire the tested six-pin keypad family

Use this table only when the candidate connector has the same explicit labels
as the tested iLiving keypad:

| Keypad connection | Bench connection |
|---|---|
| `+5V` | Regulated `+5V` supply output |
| `GND` | Supply negative **and** Waveshare `GND` |
| `485A-` | Waveshare `A+` |
| `485A+` | Waveshare `B-` |
| `485B-` | Leave disconnected |
| `485B+` | Leave disconnected |

Leave all SWD/debug pins disconnected. Do not add termination for the initial
short-cable test.

RS-485 `A` and `B` label conventions vary by manufacturer. The crossed mapping
above is the mapping validated with this keypad and Waveshare combination. If
power is verified and the keypad runs but the emulator receives no requests,
power down and swap only the two RS-485 data wires for one retry. Never swap or
guess the supply wires.

For an unlabeled or different connector, do not use this table. Determine its
power and differential-pair pinout first with documentation and passive
measurements.

## Stage 1: Capture startup and normal operation

Connect the Waveshare to the PC but leave keypad power off. Start the emulator,
substituting the detected port:

```powershell
powershell -NoProfile -ExecutionPolicy Bypass -File ".\run-pump-emulator.ps1" `
  -Port COM3 -VerboseFrames -LogFile "keypad-compat-normal.log"
```

Now turn on only the keypad's regulated bench supply. Starting the emulator
first ensures the startup requests are recorded.

The tested iLiving keypad produces behavior similar to:

```text
RX seq=0x01 status=0x00 demand=0x1770/3450rpm
TX seq=0x01 fault=0x00 accepted=0x1770 actual=0x0000 state=RAMPING corrupted=false
[ONLINE] ... requests=32 replies=32 dropped=0 bad_rx=0
```

Expected observations:

- `requests` and `replies` begin increasing at roughly 16 per second.
- Each valid request has the `01 70` header and a new sequence number.
- `bad_rx` remains zero or very low.
- The tested keypad starts its prime cycle and requests `0x1770`, which maps to
  3450 RPM.
- The keypad accepts the simulated actual-speed ramp instead of remaining in a
  communication-error state.

Press `S` in the emulator console at any time to print the current counters and
demand. Press `Q` to stop cleanly and write final statistics to the log.

## Stage 2: Exercise keypad commands

While the normal emulator is running:

1. Press each speed-preset button and then press `S` in the emulator console.
   Record the demand RPM shown for each button.
2. Use the keypad's custom-speed controls, if present. Confirm that the demand
   changes in the console.
3. Press the keypad power button once. A compatible keypad should begin sending
   a zero demand and the emulator should report `STOPPING`, then `STOPPED`.
4. Press power again. It should return to a nonzero demand; the tested keypad
   starts prime again.

Preset values may have been reprogrammed by the owner, so exact preset RPM is
not a compatibility requirement. The important evidence is that button actions
change the validated request's demand field and that stop produces zero.

## Stage 3: Verify reply and fault decoding

Stop the normal emulator with `Q`, then start the keypad-aware fault sequence:

```powershell
powershell -NoProfile -ExecutionPolicy Bypass -File ".\run-pump-emulator.ps1" `
  -Port COM3 -KeypadFaultDemo -FaultHoldSeconds 3 `
  -KeypadRecoverySeconds 2 -LogFile "keypad-compat-faults.log"
```

The emulator cycles through `E001`, `E002`, `E006`, `E009`, `E010`, `E011`,
`E013`, `E014`, `E018`, `E021`, and `E048`. For each code:

1. Confirm that the same code appears on the keypad.
2. Wait until the console says the fault replies were cleared.
3. Press keypad power once to acknowledge the fault and produce zero demand.
4. Press power a second time to restart.

The emulator waits for that zero-demand acknowledgement and subsequent restart
before advancing. Press `Q` after the final code, or add
`-ExitAfterFaultDemo` to exit automatically after the last successful restart.

Displaying the correct injected codes is strong evidence that the keypad parses
the same 38-byte reply layout, not merely the same request format.

## Interpret the result

### Strong match

Classify the keypad as a strong protocol match when all of these are true:

- Valid requests are accepted continuously at 38400 baud.
- Requests and replies stay approximately equal with few or no invalid frames.
- Sequence numbers increment and wrap normally.
- Keypad buttons produce sensible demand changes, including zero for stop.
- The keypad displays simulated speed/state changes.
- Injected fault codes appear correctly and follow the two-press recovery flow.

This is enough to add the keypad as **bench-confirmed**. The associated pump
still requires a passive bus capture before any command is transmitted to it.

### Partial match

If requests validate but the keypad rejects replies, shows incorrect speed, or
misidentifies faults, report a partial match. It may share the request protocol
but use a different 38-byte reply revision.

### No match

Do not classify the keypad as compatible when:

- no requests validate after power and polarity have been verified;
- traffic uses a different baud rate, frame length, header, checksum, or CRC;
- demand changes cannot be correlated with keypad actions; or
- the keypad never accepts replies from the emulator.

Do not modify random reply bytes to make an unknown keypad react. Capture its
traffic passively and implement a separate protocol variant.

## Troubleshooting order

1. Confirm the correct COM port and close PulseView or any other program using
   it.
2. Confirm the keypad is powered from its verified supply and shares ground
   with the Waveshare.
3. Confirm the emulator was running before keypad power was applied.
4. Power down and swap only the two RS-485 data wires once.
5. Run with `-VerboseFrames` and inspect `bad_rx` and request counters.
6. If requests remain at zero, attach a logic analyzer passively and determine
   baud rate, polarity, active pair, and frame length before further testing.

## Compatibility report template

Include the two emulator logs and fill in:

```text
Brand and pump model:
Keypad part/revision number:
Manual URL and revision:
Connector labels:
Verified keypad supply voltage:
Observed supply current:
USB-RS485 adapter model:
Working A/B mapping:
Validated request count:
Invalid request count:
Approximate requests per second:
Startup demand:
Preset demands:
Stop demand reached zero: yes/no
Speed/state reply accepted: yes/no
Fault codes displayed correctly:
Two-press fault recovery observed: yes/no
Result: strong match / partial match / no match
Notes:
```

Do not include Wi-Fi credentials, API keys, extracted proprietary firmware, or
photos containing personal information in a public report.

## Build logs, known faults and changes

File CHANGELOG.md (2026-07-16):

# Changelog

## v0.1.0 - 2026-07-15

First public-ready release of the independently implemented iLiving/Lingxiao
keypad-bus controller and emulator.

### Confirmed hardware

- iLiving `ILG8PP390-VS` pump and its original detachable keypad
- M5Stack AtomS3 with Atomic RS485 Base controlling the real pump
- Waveshare USB TO RS485 adapter controlling the real pump from Windows
- FX2LP Saleae-compatible logic analyzer for passive bus capture
- Original keypad and AtomS3 tested independently against the PC pump emulator

### Included

- Validated 38400-baud request/reply framing, additive checksums, and Modbus CRC
- Real-pump stop, restart, and 1000-3450 RPM demand control
- ESPHome entities, web interface, screen status, five speed levels, and
  state-aware button controls
- Stateful PC emulator with speed ramping, communication failures, and all 11
  documented keypad fault codes
- Offline keypad compatibility procedure, protocol tests, hardware photos, and
  M5Stack adapter-plate CAD

### Limitations

- Only the iLiving `ILG8PP390-VS` is confirmed against a real pump. Related
  Lingxiao and rebadged models remain candidates until their traffic is
  captured and compared.
- The normal keypad protocol uses the `485A` pair. The separate `485B` firmware
  path has not been characterized.
- The original keypad must be disconnected before the AtomS3, Waveshare, or
  another controller transmits on the pump bus.
- The supplied AtomS3 YAML targets the AtomS3 and Atomic RS485 Base pinout. It
  is not a generic ESP32 configuration.
- The PC emulator validates protocol and user-interface behavior; it does not
  reproduce the pump's electrical power stage, motor, or physical hazards.
- The default ESPHome startup mode is `STOPPED`, so rebooting the controller
  while connected sends a stop demand after the startup delay.
- Extracted OEM firmware is intentionally excluded. Only independently written
  code, protocol documentation, and firmware-analysis metadata are published.

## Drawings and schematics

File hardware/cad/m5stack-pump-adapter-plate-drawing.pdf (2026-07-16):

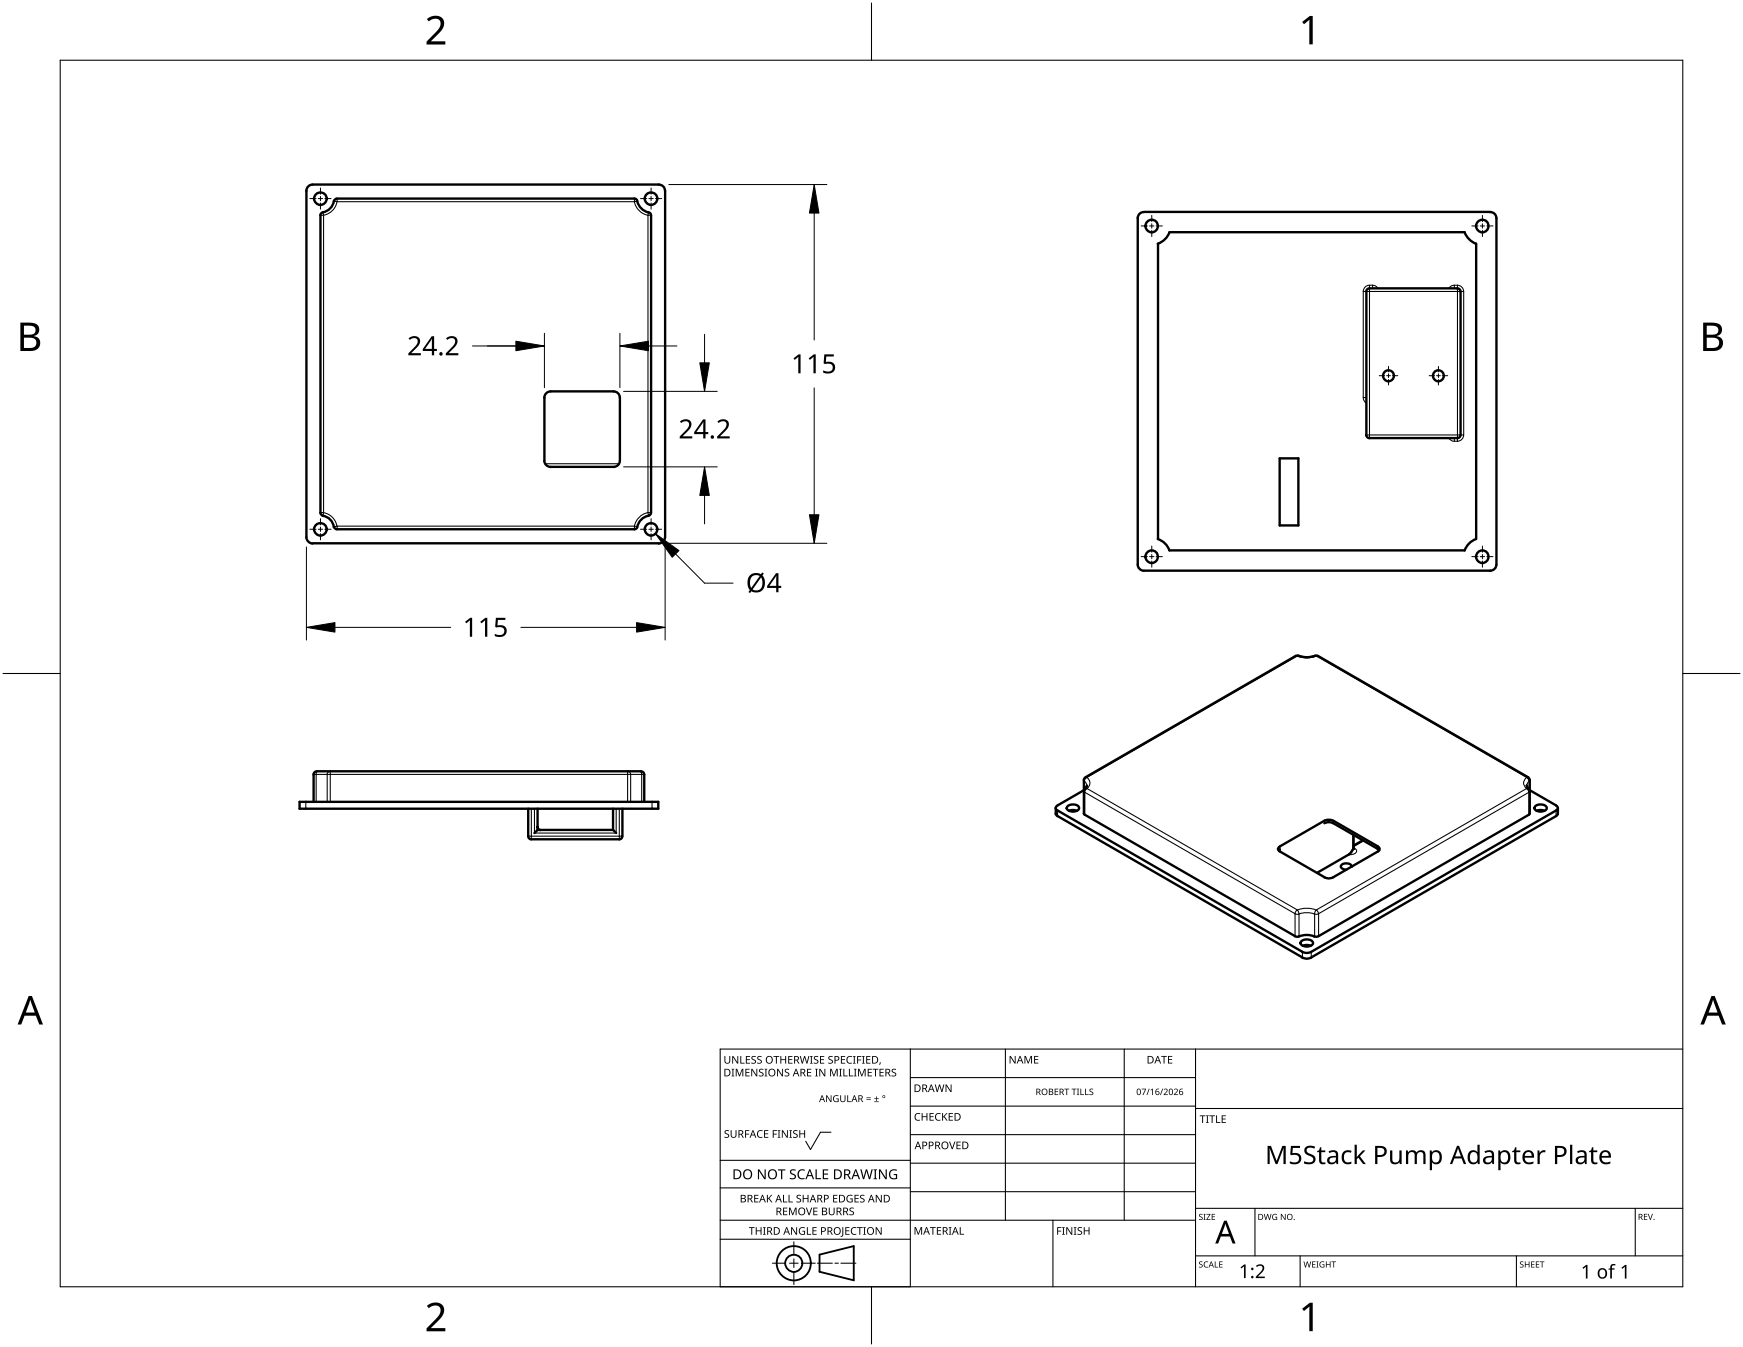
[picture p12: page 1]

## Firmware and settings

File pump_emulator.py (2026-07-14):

#!/usr/bin/env python3
"""Emulate an iLiving ILG8PP390-VS pump for a keypad or controller."""

from __future__ import annotations

import argparse
from dataclasses import dataclass
from datetime import datetime
import os
from pathlib import Path
import sys
import time
from typing import Iterable


REQUEST_SIZE = 14
REPLY_SIZE = 38
MAX_PROTOCOL_VALUE = 6000
MAX_RPM = 3450.0

FAULT_DESCRIPTIONS = {
    1: "IPM module failure",
    2: "Output current exceeds limit",
    6: "Input voltage too high",
    9: "Input voltage too low",
    10: "Inverter overload",
    11: "Motor overload",
    13: "Output phase loss or imbalance",
    14: "Inverter overheating",
    18: "Current sampling circuit failure",
    21: "Display board EEPROM or connection failure",
    48: "PFC overcurrent or PFC circuit failure",
}
FAULT_CYCLE = tuple(FAULT_DESCRIPTIONS)

# Complete pump reply captured at a stable 1800 RPM. Fields changed for each
# request are sequence, fault, accepted demand, actual speed, and demand echo.
REPLY_TEMPLATE = bytes.fromhex(
    "01 70 01 00 00 0C 00 65 00 02 00 65 0C 3A 0C 39 "
    "0A 7F 00 E4 0C 9F 01 0D 01 90 01 5F 00 45 00 00 "
    "0C 3A 77 05 85 76"
)


def modbus_crc16(data: bytes | bytearray | memoryview) -> int:
    crc = 0xFFFF
    for value in data:
        crc ^= value
        for _ in range(8):
            if crc & 1:
                crc = (crc >> 1) ^ 0xA001
            else:
                crc >>= 1
    return crc & 0xFFFF


def read_be16(data: bytes | bytearray, offset: int) -> int:
    return (data[offset] << 8) | data[offset + 1]


def write_be16(data: bytearray, offset: int, value: int) -> None:
    data[offset] = (value >> 8) & 0xFF
    data[offset + 1] = value & 0xFF


def rpm_to_value(rpm: float) -> int:
    rpm = max(0.0, min(MAX_RPM, rpm))
    return int(rpm * MAX_PROTOCOL_VALUE / MAX_RPM)


def value_to_rpm(value: int) -> float:
    value = max(0, min(MAX_PROTOCOL_VALUE, value))
    return value * MAX_RPM / MAX_PROTOCOL_VALUE


@dataclass(frozen=True)
class PumpRequest:
    sequence: int
    status: int
    demand_value: int
    raw: bytes

    @property
    def demand_rpm(self) -> float:
        return value_to_rpm(self.demand_value)


def decode_request(frame: bytes) -> PumpRequest:
    if len(frame) != REQUEST_SIZE:
        raise ValueError(f"request must be {REQUEST_SIZE} bytes")
    if frame[0:2] != b"\x01\x70":
        raise ValueError("request header is not 01 70")
    if frame[4:8] != b"\x00\x0c\x00\x00":
        raise ValueError("request shape bytes are invalid")

    expected_sum = sum(frame[:10]) & 0xFFFF
    wire_sum = frame[10] | (frame[11] << 8)
    if wire_sum != expected_sum:
        raise ValueError("request additive checksum is invalid")

    expected_crc = modbus_crc16(frame[:12])
    wire_crc = frame[12] | (frame[13] << 8)
    if wire_crc != expected_crc:
        raise ValueError("request Modbus CRC-16 is invalid")

    return PumpRequest(
        sequence=frame[2],
        status=frame[3],
        demand_value=read_be16(frame, 8),
        raw=frame,
    )


def build_reply(
    sequence: int,
    fault_code: int,
    accepted_value: int,
    actual_value: int,
    echoed_value: int,
) -> bytes:
    frame = bytearray(REPLY_TEMPLATE)
    frame[2] = sequence & 0xFF
    frame[3] = fault_code & 0xFF
    write_be16(frame, 12, accepted_value & 0xFFFF)
    write_be16(frame, 14, actual_value & 0xFFFF)
    write_be16(frame, 32, echoed_value & 0xFFFF)

    additive = sum(frame[:34]) & 0xFFFF
    frame[34] = additive & 0xFF
    frame[35] = (additive >> 8) & 0xFF
    crc = modbus_crc16(frame[:36])
    frame[36] = crc & 0xFF
    frame[37] = (crc >> 8) & 0xFF
    return bytes(frame)


def validate_reply(frame: bytes) -> bool:
    if len(frame) != REPLY_SIZE:
        return False
    if frame[0:2] != b"\x01\x70" or frame[4:6] != b"\x00\x0c":
        return False
    if (frame[34] | (frame[35] << 8)) != (sum(frame[:34]) & 0xFFFF):
        return False
    return (frame[36] | (frame[37] << 8)) == modbus_crc16(frame[:36])


class RequestStreamParser:
    """Recover validated 14-byte requests from arbitrary serial chunks."""

    def __init__(self) -> None:
        self.buffer = bytearray()
        self.discarded_bytes = 0
        self.invalid_candidates = 0

    def feed(self, data: bytes) -> list[PumpRequest]:
        self.buffer.extend(data)
        requests: list[PumpRequest] = []

        while len(self.buffer) >= 2:
            header = self.buffer.find(b"\x01\x70")
            if header < 0:
                keep = 1 if self.buffer[-1] == 0x01 else 0
                self.discarded_bytes += len(self.buffer) - keep
                if keep:
                    self.buffer[:] = b"\x01"
                else:
                    self.buffer.clear()
                break

            if header:
                del self.buffer[:header]
                self.discarded_bytes += header

            if len(self.buffer) < REQUEST_SIZE:
                break

            candidate = bytes(self.buffer[:REQUEST_SIZE])
            try:
                request = decode_request(candidate)
            except ValueError:
                del self.buffer[0]
                self.discarded_bytes += 1
                self.invalid_candidates += 1
                continue

            del self.buffer[:REQUEST_SIZE]
            requests.append(request)

        return requests


class PumpModel:
    def __init__(self, initial_rpm: float, ramp_rpm_per_second: float) -> None:
        self.actual_rpm = max(0.0, min(MAX_RPM, initial_rpm))
        self.target_rpm = self.actual_rpm
        self.accepted_value = rpm_to_value(self.target_rpm)
        self.ramp_rpm_per_second = max(0.0, ramp_rpm_per_second)
        self.fault_code = 0
        self.last_update: float | None = None

    def _advance(self, now: float) -> None:
        if self.last_update is None:
            self.last_update = now
            return

        elapsed = max(0.0, now - self.last_update)
        self.last_update = now
        difference = self.target_rpm - self.actual_rpm
        if self.ramp_rpm_per_second == 0 or abs(difference) <= self.ramp_rpm_per_second * elapsed:
            self.actual_rpm = self.target_rpm
            return

        direction = 1.0 if difference > 0 else -1.0
        self.actual_rpm += direction * self.ramp_rpm_per_second * elapsed

    def apply_request(self, request: PumpRequest, now: float) -> tuple[int, int]:
        self._advance(now)
        requested = min(request.demand_value, MAX_PROTOCOL_VALUE)
        self.accepted_value = 0 if self.fault_code else requested
        self.target_rpm = value_to_rpm(self.accepted_value)
        if self.ramp_rpm_per_second == 0:
            self.actual_rpm = self.target_rpm
        return self.accepted_value, rpm_to_value(self.actual_rpm)

    def force_stopped(self, now: float) -> None:
        self.actual_rpm = 0.0
        self.last_update = now

    def state_name(self) -> str:
        if self.fault_code:
            return f"E{self.fault_code:03d}"
        if self.accepted_value == 0:
            return "STOPPED" if self.actual_rpm < 1.0 else "STOPPING"
        if abs(self.actual_rpm - self.target_rpm) <= 2.0:
            return "RUNNING"
        return "RAMPING"


@dataclass
class RuntimeState:
    online: bool = True
    drop_next: int = 0
    corrupt_next: int = 0
    verbose: bool = False
    quit_requested: bool = False


@dataclass
class Statistics:
    requests: int = 0
    replies: int = 0
    dropped: int = 0
    corrupted: int = 0
    sequence_jumps: int = 0
    last_sequence: int | None = None
    last_demand_value: int = 0


class FaultSequence:
    """Schedule fault/clear transitions against a monotonic clock."""

    def __init__(
        self,
        codes: Iterable[int],
        start_delay: float,
        fault_duration: float,
        clear_duration: float,
    ) -> None:
        self.codes = tuple(codes)
        if not self.codes:
            raise ValueError("fault sequence requires at least one code")
        if any(code < 1 or code > 255 for code in self.codes):
            raise ValueError("fault sequence codes must be between 1 and 255")
        if start_delay < 0 or fault_duration <= 0 or clear_duration < 0:
            raise ValueError("fault timing values are invalid")

        cursor = start_delay
        events: list[tuple[float, int]] = []
        for code in self.codes:
            events.append((cursor, code))
            cursor += fault_duration
            events.append((cursor, 0))
            cursor += clear_duration

        self.events = tuple(events)
        self.complete_offset = cursor
        self.started_at: float | None = None
        self.next_event = 0
        self.completed = False

    def start(self, now: float) -> None:
        self.started_at = now
        self.next_event = 0
        self.completed = False

    def update(self, now: float) -> tuple[list[int], bool]:
        if self.started_at is None:
            raise RuntimeError("fault sequence has not been started")
        if self.completed:
            return [], False

        elapsed = max(0.0, now - self.started_at)
        transitions: list[int] = []
        while self.next_event < len(self.events) and elapsed >= self.events[self.next_event][0]:
            transitions.append(self.events[self.next_event][1])
            self.next_event += 1

        completed_now = self.next_event == len(self.events) and elapsed >= self.complete_offset
        if completed_now:
            self.completed = True
        return transitions, completed_now


class KeypadFaultSequence:
    """Advance faults only after the keypad acknowledges and restarts."""

    def __init__(
        self,
        codes: Iterable[int],
        start_delay: float,
        fault_duration: float,
        recovery_duration: float,
    ) -> None:
        self.codes = tuple(codes)
        if not self.codes:
            raise ValueError("keypad fault sequence requires at least one code")
        if any(code < 1 or code > 255 for code in self.codes):
            raise ValueError("keypad fault sequence codes must be between 1 and 255")
        if start_delay < 0 or fault_duration <= 0 or recovery_duration < 0:
            raise ValueError("keypad fault timing values are invalid")

        self.start_delay = start_delay
        self.fault_duration = fault_duration
        self.recovery_duration = recovery_duration
        self.index = 0
        self.phase = "idle"
        self.deadline = 0.0
        self.saw_zero_demand = False
        self.completed = False

    def start(self, now: float) -> None:
        self.index = 0
        self.phase = "before_fault"
        self.deadline = now + self.start_delay
        self.saw_zero_demand = False
        self.completed = False

    def update(self, now: float, demand_value: int) -> tuple[list[tuple[str, int]], bool]:
        if self.phase == "idle":
            raise RuntimeError("keypad fault sequence has not been started")
        if self.completed:
            return [], False

        events: list[tuple[str, int]] = []
        completed_now = False

        if self.phase in ("before_fault", "recovering") and now >= self.deadline:
            code = self.codes[self.index]
            events.append(("set", code))
            self.phase = "fault"
            self.deadline = now + self.fault_duration
            self.saw_zero_demand = demand_value == 0
        elif self.phase == "fault":
            if demand_value == 0:
                self.saw_zero_demand = True
            if now >= self.deadline:
                events.append(("clear", 0))
                self.phase = "waiting_for_restart"
        elif self.phase == "waiting_for_restart":
            if demand_value == 0:
                self.saw_zero_demand = True
            elif self.saw_zero_demand:
                events.append(("restart", self.codes[self.index]))
                self.index += 1
                if self.index == len(self.codes):
                    self.completed = True
                    completed_now = True
                else:
                    self.phase = "recovering"
                    self.deadline = now + self.recovery_duration

        return events, completed_now


class EventLog:
    def __init__(self, path: Path) -> None:
        self.path = path
        self.started = time.monotonic()
        self.file = path.open("w", encoding="ascii", newline="\n")

    def write(self, event: str, details: str, raw: bytes | None = None) -> None:
        elapsed_ms = (time.monotonic() - self.started) * 1000.0
        suffix = f"  {raw.hex(' ').upper()}" if raw is not None else ""
        self.file.write(f"{elapsed_ms:11.2f}  {event:<12} {details}{suffix}\n")
        self.file.flush()

    def close(self) -> None:
        self.file.close()


def describe_fault(code: int) -> str:
    if not code:
        return "None"
    return f"E{code:03d}: {FAULT_DESCRIPTIONS.get(code, 'Unknown pump fault/status')}"


def print_status(
    model: PumpModel,
    runtime: RuntimeState,
    stats: Statistics,
    parser: RequestStreamParser,
) -> None:
    link = "ONLINE" if runtime.online else "OFFLINE (replies suppressed)"
    print(
        f"[{link}] state={model.state_name()} demand={value_to_rpm(stats.last_demand_value):.0f} "
        f"accepted={value_to_rpm(model.accepted_value):.0f} actual={model.actual_rpm:.0f} RPM "
        f"fault={describe_fault(model.fault_code)} requests={stats.requests} replies={stats.replies} "
        f"dropped={stats.dropped} bad_rx={parser.invalid_candidates}"
    )


def read_console_keys() -> Iterable[str]:
    if os.name != "nt" or not sys.stdin.isatty():
        return ()
    import msvcrt

    keys: list[str] = []
    while msvcrt.kbhit():
        key = msvcrt.getwch()
        if key in ("\x00", "\xe0"):
            if msvcrt.kbhit():
                msvcrt.getwch()
            continue
        keys.append(key.lower())
    return keys


def handle_key(
    key: str,
    model: PumpModel,
    runtime: RuntimeState,
    stats: Statistics,
    parser: RequestStreamParser,
) -> None:
    if key == "q":
        runtime.quit_requested = True
    elif key == "o":
        runtime.online = not runtime.online
        print(f"Emulated link is now {'ONLINE' if runtime.online else 'OFFLINE'}.")
    elif key == "f":
        try:
            current = FAULT_CYCLE.index(model.fault_code)
            model.fault_code = FAULT_CYCLE[(current + 1) % len(FAULT_CYCLE)]
        except ValueError:
            model.fault_code = FAULT_CYCLE[0]
        print(f"Injecting {describe_fault(model.fault_code)}.")
    elif key == "c":
        model.fault_code = 0
        print("Fault cleared. The attached controller must issue RUN again after stopping.")
    elif key == "d":
        runtime.drop_next += 1
        print(f"Will drop the next {runtime.drop_next} reply/replies.")
    elif key == "x":
        runtime.corrupt_next += 1
        print(f"Will corrupt CRC on the next {runtime.corrupt_next} reply/replies.")
    elif key == "r":
        model.force_stopped(time.monotonic())
        print("Actual RPM forced to zero; accepted demand is unchanged.")
    elif key == "v":
        runtime.verbose = not runtime.verbose
        print(f"Per-frame console logging {'enabled' if runtime.verbose else 'disabled'}.")
    elif key == "s":
        print_status(model, runtime, stats, parser)
    elif key in ("h", "?"):
        print("Keys: S=status F=next fault C=clear O=offline D=drop X=bad CRC R=zero RPM V=verbose Q=quit")


def build_argument_parser() -> argparse.ArgumentParser:
    parser = argparse.ArgumentParser(
        description="Emulate the iLiving pump for a keypad or controller through a USB-RS485 adapter."
    )
    parser.add_argument("--port", default="COM3", help="Waveshare serial port (default: COM3)")
    parser.add_argument("--baud", type=int, default=38400, help="Serial baud rate (default: 38400)")
    parser.add_argument(
        "--reply-delay-ms",
        type=float,
        default=5.0,
        help="Delay after a complete request before transmitting (default: 5 ms)",
    )
    parser.add_argument(
        "--ramp-rpm-per-sec",
        type=float,
        default=1200.0,
        help="Acceleration and deceleration rate; zero is immediate (default: 1200)",
    )
    parser.add_argument("--initial-rpm", type=float, default=0.0, help="Initial simulated actual RPM")
    parser.add_argument("--fault-code", type=int, default=0, help="Initial reply fault/status byte")
    parser.add_argument(
        "--fault-demo",
        action="store_true",
        help="Cycle through every documented keypad fault, clearing between codes",
    )
    parser.add_argument(
        "--keypad-fault-demo",
        action="store_true",
        help="Cycle faults only after the original keypad is cleared and restarted",
    )
    parser.add_argument(
        "--fault-start-delay-seconds",
        type=float,
        default=2.0,
        help="Online settling time before the fault demo starts (default: 2)",
    )
    parser.add_argument(
        "--fault-hold-seconds",
        type=float,
        default=3.0,
        help="Seconds to hold each injected fault (default: 3)",
    )
    parser.add_argument(
        "--fault-clear-seconds",
        type=float,
        default=1.0,
        help="Seconds to send clear replies between faults (default: 1)",
    )
    parser.add_argument(
        "--keypad-recovery-seconds",
        type=float,
        default=2.0,
        help="Clear running time before the next keypad fault (default: 2)",
    )
    parser.add_argument(
        "--exit-after-fault-demo",
        action="store_true",
        help="Exit after the final fault has been cleared",
    )
    parser.add_argument(
        "--summary-interval",
        type=float,
        default=2.0,
        help="Seconds between console summaries; zero disables them",
    )
    parser.add_argument("--verbose", action="store_true", help="Print every request and reply")
    parser.add_argument("--log", type=Path, help="ASCII event log path")
    parser.add_argument("--list-ports", action="store_true", help="List serial ports and exit")
    parser.add_argument("--list-faults", action="store_true", help="List documented keypad fault codes and exit")
    return parser


def list_serial_ports() -> int:
    try:
        from serial.tools import list_ports
    except ImportError:
        print("pyserial is not installed. Use the project's ESPHome Python environment.", file=sys.stderr)
        return 2

    ports = list(list_ports.comports())
    if not ports:
        print("No serial ports detected.")
        return 0
    for port in ports:
        print(f"{port.device:<8} {port.description} [{port.hwid}]")
    return 0


def list_faults() -> int:
    print("Code  Keypad fault description")
    for code, description in FAULT_DESCRIPTIONS.items():
        print(f"E{code:03d}  {description}")
    return 0
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

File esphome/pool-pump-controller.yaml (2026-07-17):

substitutions:
  pump_speed_level_1: "1000"
  pump_speed_level_2: "1400"
  pump_speed_level_3: "1800"
  pump_speed_level_4: "2500"
  pump_speed_level_5: "3450"
  display_dim_after: 1min
  display_sleep_after_dimming: 4min
  display_dim_percent: "20"

esphome:
  name: pool-pump-controller
  friendly_name: Pool Pump Controller
  on_boot:
    - priority: -100
      then:
        - delay: 200ms
        - lambda: |-
            id(display_ready) = true;
        # The AtomS3 LCD wake command must run after SPI/display setup.
        - script.execute: display_wake

esp32:
  board: m5stack-atoms3
  framework:
    type: arduino

logger:
  level: DEBUG
  hardware_uart: USB_SERIAL_JTAG

api:
  encryption:
    key: !secret api_encryption_key

ota:
  - platform: esphome
    password: !secret ota_password

web_server:
  port: 80

wifi:
  ssid: !secret wifi_ssid
  password: !secret wifi_password
  ap:
    ssid: Pool-Pump-Controller
    password: !secret fallback_ap_password

captive_portal:

external_components:
  - source: components
    components: [iliving_pump]

uart:
  id: rs485_uart
  baud_rate: 38400
  data_bits: 8
  parity: NONE
  stop_bits: 1
  rx_pin: GPIO5
  tx_pin: GPIO6
  rx_buffer_size: 256

iliving_pump:
  id: pump_controller
  uart_id: rs485_uart
  poll_interval: 61ms
  reply_timeout: 55ms
  offline_timeout: 500ms
  telemetry_interval: 500ms
  startup_delay: 1s

  # STOPPED is deterministic and fail-safe: every Atom boot commands zero RPM.
  # PASSIVE sends nothing until Pump Run is explicitly changed.
  startup_mode: STOPPED
  initial_target_rpm: ${pump_speed_level_3}
  stop_on_communication_loss: true

  run:
    name: Pump Run
    id: pump_run
    on_turn_on:
      - script.execute: display_wake
    on_turn_off:
      - script.execute: display_wake
  demand_rpm:
    name: Pump Demand RPM
    id: pump_demand_rpm
    on_value:
      - script.execute: display_wake
  actual_rpm:
    name: Pump RPM
    id: pump_rpm
  accepted_rpm:
    name: Pump Accepted RPM
    id: pump_accepted_rpm
  online:
    name: Pump Communication
    id: pump_online
    on_press:
      - script.execute: display_wake
    on_release:
      - script.execute: display_wake
  motor_running:
    name: Pump Motor Running
    id: pump_motor_running
    on_press:
      - script.execute: display_wake
    on_release:
      - script.execute: display_wake
  control_active:
    name: Pump Controller Active
    id: pump_control_active
  fault:
    name: Pump Fault
    id: pump_fault
    on_press:
      - script.execute: display_wake
    on_release:
      - script.execute: display_wake
  fault_code:
    name: Pump Fault Code
    id: pump_fault_code
  status:
    name: Pump Status
    id: pump_status
  fault_text:
    name: Pump Fault Description
    id: pump_fault_text
  valid_replies:
    name: Pump Valid Replies
    id: pump_valid_replies
  missed_replies:
    name: Pump Missed Replies
    id: pump_missed_replies
  discarded_bytes:
    name: Pump Discarded UART Bytes
    id: pump_discarded_bytes

binary_sensor:
  - platform: gpio
    id: atoms3_button
    name: AtomS3 Button
    pin:
      number: GPIO41
      inverted: true
      mode:
        input: true
        pullup: true
    filters:
      - delayed_on: 30ms
      - delayed_off: 30ms
    on_multi_click:
      # A quick press starts a stopped pump at the selected speed. Once running,
      # quick presses select the next of five pump-speed presets.
      - timing:
          - ON for at most 800ms
          - OFF for at least 50ms
        then:
          - if:
              condition:
                lambda: return id(display_sleeping);
              then:
                # The first short press only wakes the screen. It must not
                # start the pump or change its selected speed.
                - script.execute: display_wake
              else:
                - if:
                    condition:
                      switch.is_off: pump_run
                    then:
                      - switch.turn_on: pump_run
                    else:
                      - number.set:
                          id: pump_demand_rpm
                          value: !lambda |-
                            const float current = id(pump_demand_rpm).state;
                            if (std::isnan(current) || current >= ${pump_speed_level_5}.0f)
                              return ${pump_speed_level_1}.0f;
                            if (current < ${pump_speed_level_2}.0f)
                              return ${pump_speed_level_2}.0f;
                            if (current < ${pump_speed_level_3}.0f)
                              return ${pump_speed_level_3}.0f;
                            if (current < ${pump_speed_level_4}.0f)
                              return ${pump_speed_level_4}.0f;
                            return ${pump_speed_level_5}.0f;
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

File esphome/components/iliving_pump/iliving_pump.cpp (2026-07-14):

#include "iliving_pump.h"

#include "esphome/core/log.h"

#include <algorithm>
#include <cmath>
#include <cstdio>
#include <cstring>

namespace esphome {
namespace iliving_pump {

static const char *const TAG = "iliving_pump";

// These fixtures come from the Waveshare script and a pump-validated 1800 RPM reply.
constexpr auto SPEED1_REQUEST_FIXTURE = protocol::build_request(0x01, 0x00, 0x0C3A);
static_assert(SPEED1_REQUEST_FIXTURE[10] == 0xC4 && SPEED1_REQUEST_FIXTURE[11] == 0x00 &&
                  SPEED1_REQUEST_FIXTURE[12] == 0xDF && SPEED1_REQUEST_FIXTURE[13] == 0x58,
              "iLiving request checksum regression");
static_assert(protocol::rpm_to_value(1400) == 0x0982, "1400 RPM scaling regression");
static_assert(protocol::rpm_to_value(1800) == 0x0C3A, "1800 RPM scaling regression");
static_assert(protocol::rpm_to_value(2000) == 0x0D96, "2000 RPM scaling regression");
static_assert(protocol::rpm_to_value(3450) == 0x1770, "3450 RPM scaling regression");

constexpr std::array<uint8_t, protocol::REPLY_SIZE> SPEED1_REPLY_FIXTURE = {
    0x01, 0x70, 0x01, 0x00, 0x00, 0x0C, 0x00, 0x65, 0x00, 0x02,
    0x00, 0x65, 0x0C, 0x3A, 0x0C, 0x39, 0x0A, 0x7F, 0x00, 0xE4,
    0x0C, 0x9F, 0x01, 0x0D, 0x01, 0x90, 0x01, 0x5F, 0x00, 0x45,
    0x00, 0x00, 0x0C, 0x3A, 0x77, 0x05, 0x85, 0x76,
};
static_assert(protocol::validate_reply(SPEED1_REPLY_FIXTURE), "iLiving reply validation regression");

void ILivingPumpRunSwitch::write_state(bool state) { this->parent_->set_run_command(state); }

void ILivingPumpDemandNumber::control(float value) { this->parent_->set_target_rpm(value); }

void ILivingPump::setup() {
  this->setup_ms_ = millis();
  this->last_tx_ms_ = this->setup_ms_;

  uint8_t stale;
  while (this->available())
    this->read_byte(&stale);

  switch (this->startup_mode_) {
    case STARTUP_MODE_STOPPED:
      this->control_active_ = true;
      this->run_requested_ = false;
      this->publish_status_("INITIALIZING");
      break;
    case STARTUP_MODE_RUNNING:
      this->control_active_ = true;
      this->run_requested_ = true;
      this->publish_status_("INITIALIZING");
      break;
    case STARTUP_MODE_PASSIVE:
    default:
      this->control_active_ = false;
      this->run_requested_ = false;
      this->publish_status_("STANDBY");
      break;
  }

  if (this->demand_rpm_number_ != nullptr)
    this->demand_rpm_number_->publish_state(this->demand_rpm_);
  if (this->run_switch_ != nullptr)
    this->run_switch_->publish_state(this->run_requested_);
  if (this->online_binary_sensor_ != nullptr)
    this->online_binary_sensor_->publish_state(false);
  if (this->motor_running_binary_sensor_ != nullptr)
    this->motor_running_binary_sensor_->publish_state(false);
  if (this->fault_binary_sensor_ != nullptr)
    this->fault_binary_sensor_->publish_state(false);
  if (this->fault_code_sensor_ != nullptr)
    this->fault_code_sensor_->publish_state(0);
  if (this->fault_text_sensor_ != nullptr)
    this->fault_text_sensor_->publish_state("None");
  this->publish_control_active_(this->control_active_);
  this->publish_diagnostics_(this->setup_ms_, true);
}

void ILivingPump::loop() {
  this->drain_uart_();
  this->parse_rx_buffer_();

  const uint32_t now = millis();
  if (this->awaiting_reply_ && (now - this->last_tx_ms_) >= this->reply_timeout_ms_) {
    this->awaiting_reply_ = false;
    this->missed_reply_count_++;
  }

  this->check_offline_(now);
  this->publish_diagnostics_(now);

  if (!this->control_active_ || (now - this->setup_ms_) < this->startup_delay_ms_)
    return;
  if (!this->awaiting_reply_ && (now - this->last_tx_ms_) >= this->poll_interval_ms_)
    this->send_request_();
}

void ILivingPump::dump_config() {
  ESP_LOGCONFIG(TAG, "iLiving ILG8PP390-VS pump controller:");
  ESP_LOGCONFIG(TAG, "  Poll interval: %u ms", this->poll_interval_ms_);
  ESP_LOGCONFIG(TAG, "  Reply timeout: %u ms", this->reply_timeout_ms_);
  ESP_LOGCONFIG(TAG, "  Offline timeout: %u ms", this->offline_timeout_ms_);
  ESP_LOGCONFIG(TAG, "  Initial target: %u RPM", this->demand_rpm_);
  ESP_LOGCONFIG(TAG, "  Startup mode: %s",
                this->startup_mode_ == STARTUP_MODE_PASSIVE
                    ? "PASSIVE"
                    : (this->startup_mode_ == STARTUP_MODE_STOPPED ? "STOPPED" : "RUNNING"));
  ESP_LOGCONFIG(TAG, "  Stop on communication loss: %s", YESNO(this->stop_on_communication_loss_));
}

void ILivingPump::set_run_command(bool run) {
  if (run && this->fault_code_ != 0) {
    ESP_LOGW(TAG, "Start rejected while pump fault E%03u is active", this->fault_code_);
    if (this->run_switch_ != nullptr)
      this->run_switch_->publish_state(false);
    return;
  }

  this->control_active_ = true;
  this->run_requested_ = run;
  this->publish_control_active_(true);
  if (this->run_switch_ != nullptr)
    this->run_switch_->publish_state(run);
  this->schedule_immediate_request_();
}

void ILivingPump::set_target_rpm(float rpm) {
  const uint16_t clamped = static_cast<uint16_t>(
      std::lround(std::max(1000.0f, std::min(3450.0f, rpm))));
  this->demand_rpm_ = clamped;
  if (this->demand_rpm_number_ != nullptr)
    this->demand_rpm_number_->publish_state(clamped);
  if (this->control_active_ && this->run_requested_)
    this->schedule_immediate_request_();
}

void ILivingPump::drain_uart_() {
  uint8_t byte;
  while (this->available()) {
    if (!this->read_byte(&byte))
      break;
    if (this->rx_length_ == this->rx_buffer_.size()) {
      this->discard_rx_prefix_(1);
      this->discarded_byte_count_++;
    }
    this->rx_buffer_[this->rx_length_++] = byte;
  }
}

void ILivingPump::parse_rx_buffer_() {
  while (this->rx_length_ >= 2) {
    size_t header = 0;
    while (header + 1 < this->rx_length_ &&
           !(this->rx_buffer_[header] == 0x01 && this->rx_buffer_[header + 1] == 0x70))
      header++;

    if (header + 1 >= this->rx_length_) {
      const bool keep_last = this->rx_buffer_[this->rx_length_ - 1] == 0x01;
      const size_t discarded = this->rx_length_ - (keep_last ? 1 : 0);
      if (keep_last)
        this->rx_buffer_[0] = 0x01;
      this->rx_length_ = keep_last ? 1 : 0;
      this->discarded_byte_count_ += discarded;
      return;
    }

    if (header > 0) {
      this->discard_rx_prefix_(header);
      this->discarded_byte_count_ += header;
    }

    if (this->have_last_request_ && this->rx_length_ >= protocol::REQUEST_SIZE &&
        std::equal(this->last_request_.begin(), this->last_request_.end(), this->rx_buffer_.begin())) {
      this->discard_rx_prefix_(protocol::REQUEST_SIZE);
      continue;
    }

    if (this->rx_length_ < protocol::REPLY_SIZE)
      return;

    std::array<uint8_t, protocol::REPLY_SIZE> frame{};
    std::copy_n(this->rx_buffer_.begin(), protocol::REPLY_SIZE, frame.begin());
    if (protocol::validate_reply(frame)) {
      this->discard_rx_prefix_(protocol::REPLY_SIZE);
      this->process_reply_(frame);
    } else {
      this->discard_rx_prefix_(1);
      this->discarded_byte_count_++;
    }
  }
}
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

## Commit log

2026-07-14 Initial ESPHome pool pump controller
    [pool-pump-controller.yaml]
2026-07-15 Update AtomS3 button controls
    [pool-pump-controller.yaml]
2026-07-15 Stop pump at long-press threshold
    [pool-pump-controller.yaml]
2026-07-16 Confirm AtomS3 control of real pump
2026-07-16 Add adapter plate CAD and hardware photos
    [m5stack-pump-adapter-plate.step]
2026-07-17 Add LCD inactivity sleep protection
    [pool-pump-controller.yaml]
